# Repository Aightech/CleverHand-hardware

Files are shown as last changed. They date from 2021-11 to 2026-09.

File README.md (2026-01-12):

# CleverHand — Hardware

This repository contains the **hardware implementation** of the CleverHand platform.

CleverHand is an open-source, modular **Human–Machine Interface (HMI) platform** designed for
research, education, and rapid prototyping in neurotechnology, robotics, and human–robot interaction.

The hardware repository provides:

* modular PCB designs (KiCad),
* mechanical integration assets,
* manufacturing outputs,
* and per-module documentation and quality metadata.

> This repository focuses **only on hardware**.
> Firmware, software, tools, and platform-level documentation live in sibling repositories.

---

## Position in the CleverHand platform

CleverHand is structured as a **hardware / firmware / software stack**:

* **Hardware** (this repo)
  Modular, chainable PCBs for sensing, actuation, and interfacing with the human body.

* **Firmware**
  Low-level drivers, bus control, synchronization, and data transport.

* **Software & SDKs**
  Host interfaces (GUI, Python, C++, LSL, ROS, etc.).

This separation allows:

* independent evolution of hardware and software,
* reproducible research setups,
* and multiple integration paths (DIY, PCBA, pre-assembled).

---

## Intended use & scope

CleverHand hardware is designed for:

* research experiments,
* educational use,
* prototyping of assistive and interactive systems.

It is **not**:

* a medical device,
* a certified clinical system,
* a consumer product.

All designs are provided **as-is**, with readiness and quality explicitly documented per module.

---

## Design goals & constraints

| Constraint | Status | Notes |
| --- | :----: | --- |
| Wearable | ⚒️ | Wireless support in progress |
| ≥16 channels | ✅ | Up to 256 channels (32 × 8)  |
| ≥2 kHz bandwidth | ✅ | Up to 2.5 kHz |
| ≥16-bit resolution  | ✅ | Up to 24-bit |
| Bipolar / monopolar | ✅ | Module-dependent |
| Modular | ✅ | 1–32 modules per bus |
| Affordable | ✅ | ~£10–£30 per module |
| Open-source | ✅ | Hardware, firmware, software |

---

## Hardware architecture overview

The hardware platform is built around a **chainable modular architecture**.

Each CleverHand system is composed of:

* a **controller** (host interface and timing),
* one **communication module** (bus arbitration),
* one or more **HMI modules**, assembled from submodules.

### Submodule types

HMI nodes are built by stacking standardized submodules:

* **Communication submodule**
  Address decoding, bus routing, chip-select handling.

* **Sensor submodule**
  Biosignal or motion acquisition (EMG, IMU, etc.).

* **Feedback submodule**
  User feedback (vibration, electrotactile stimulation, LEDs).

* **Interface submodule**
  Physical interface to the body (dry electrodes, jack, flex PCB).

This structure allows:

* rapid reconfiguration,
* high channel density,
* reuse of validated building blocks.

---

## Module catalog (hardware)

> The table below lists **implemented hardware designs**.
> Readiness (prototype / reference) and quality status are tracked via
> `description.yaml`, QC artifacts, and the generated catalog — not inferred from this table.

| Module | Description | Image | Documentation |
| --- | --- | --- | --- |
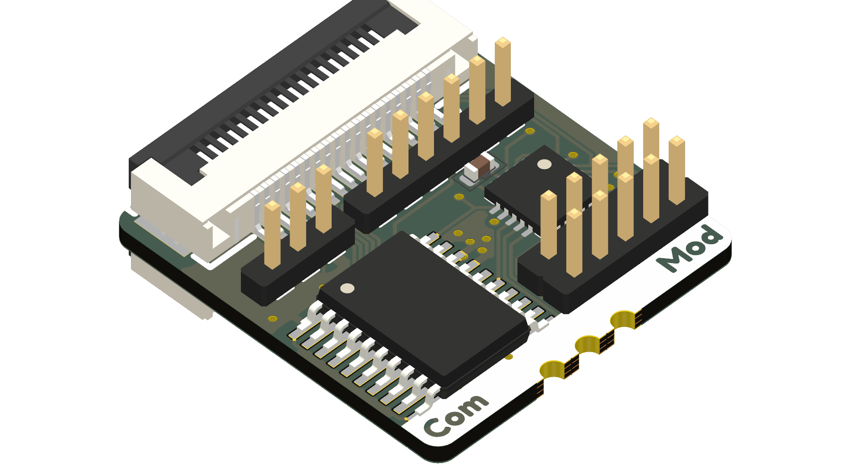
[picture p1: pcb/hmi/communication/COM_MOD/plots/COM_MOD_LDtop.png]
| Communication (COM_MOD) | Bus communication and address decoding |  | [README](pcb/hmi/communication/COM_MOD/README.md) |
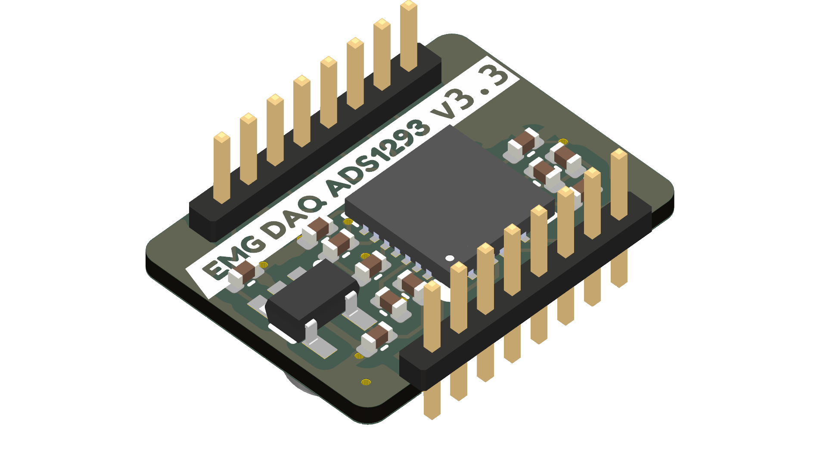
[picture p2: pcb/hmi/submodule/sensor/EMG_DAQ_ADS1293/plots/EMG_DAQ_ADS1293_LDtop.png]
| EMG ADS1293 | 5-channel EMG acquisition |  | [README](pcb/hmi/submodule/sensor/EMG_DAQ_ADS1293/README.md) |
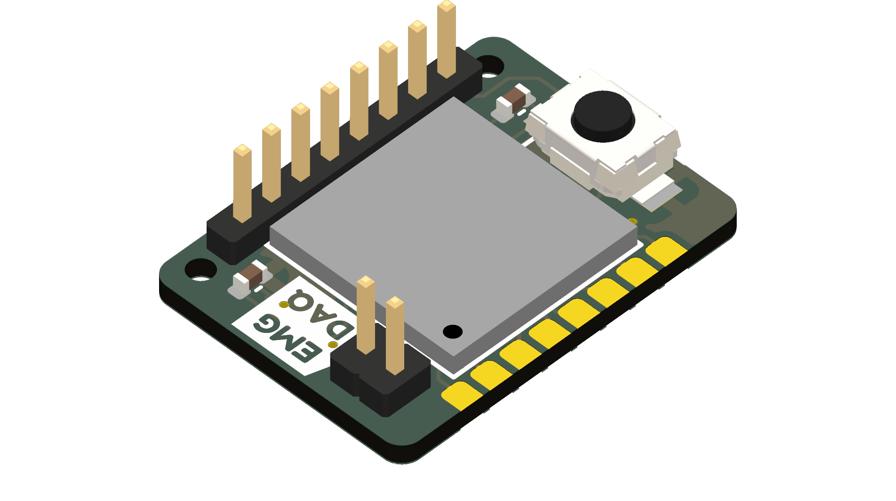
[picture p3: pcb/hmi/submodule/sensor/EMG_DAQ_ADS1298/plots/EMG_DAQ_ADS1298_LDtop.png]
| EMG ADS1298 | 8-channel EMG acquisition |  | [README](pcb/hmi/submodule/sensor/EMG_DAQ_ADS1298/README.md) |
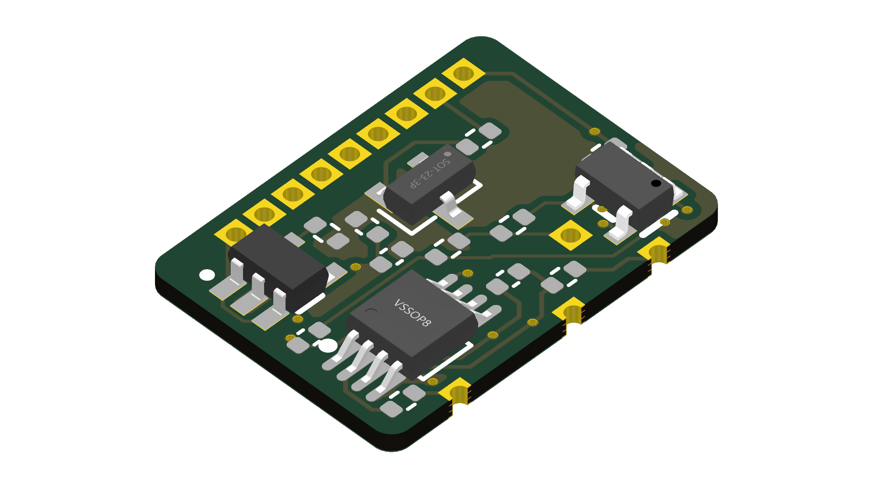
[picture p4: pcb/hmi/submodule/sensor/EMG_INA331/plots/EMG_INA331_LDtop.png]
| EMG INA331 | Single-channel EMG + IMU |  | [README](pcb/hmi/submodule/sensor/EMG_INA331/README.md) |
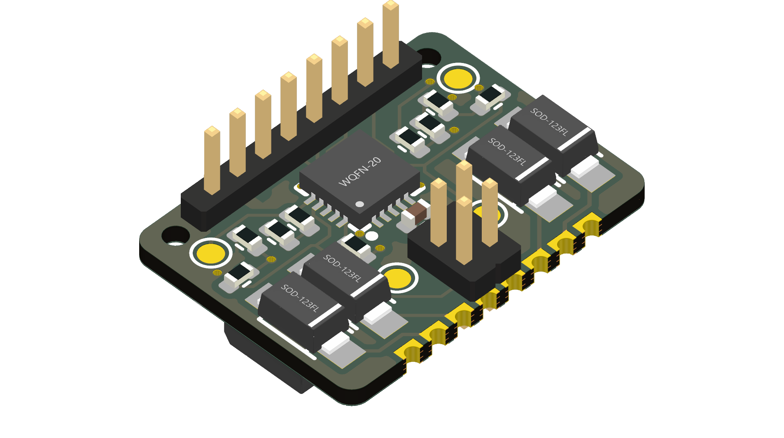
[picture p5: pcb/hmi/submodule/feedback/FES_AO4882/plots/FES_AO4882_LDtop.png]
| FES AO4882 | Electrotactile stimulation |  | [README](pcb/hmi/submodule/feedback/FES_AO4882/README.md) |
| IMU ICM-20948 | 9-axis IMU |  | [README](pcb/hmi/submodule/sensor/IMU_ICM20948/README.md) |
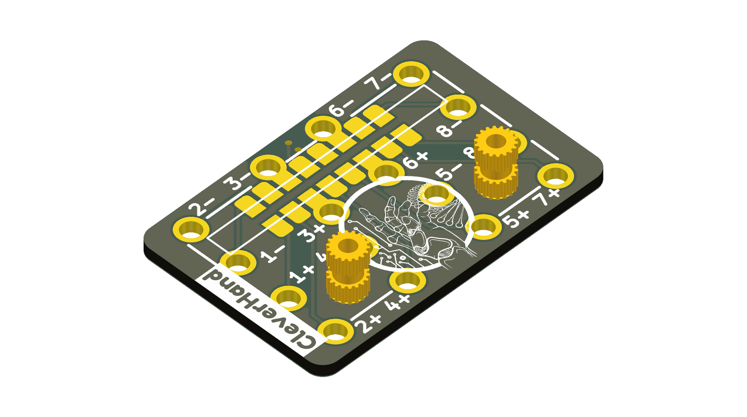
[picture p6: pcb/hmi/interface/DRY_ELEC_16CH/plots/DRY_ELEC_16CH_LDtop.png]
| Dry electrodes (16ch) | Rigid dry electrode interface |  | [README](pcb/hmi/interface/DRY_ELEC_16CH/README.md) |

---

## Bus architecture

CleverHand uses a **shared bus architecture** combining:

* a 5-bit address bus,
* SPI for high-rate data transfer,
* I²C for identification and configuration.

Each communication module:

* monitors the address bus,
* activates the chip-select of the targeted submodule,
* routes SPI transactions accordingly.

System diagram

---

## Addressing & initialization

Module addressing is determined during an initialization phase based on
**physical position in the chain**.

Current status:

* deterministic addressing: **implemented**
* dynamic hot-plugging: **not yet supported**

Future work will refine:

* formal initialization protocol documentation,
* dynamic re-enumeration strategies.

Communication diagram

---

## Evaluation, QC & readiness

Hardware quality and maturity are **explicitly tracked**, not implied.

For each module:

* readiness level is declared in `description.yaml`,
* QC profiles and reports live in the module’s `qc/` folder,
* catalog readiness is generated automatically.

Only **REFERENCE-level modules** are considered stable and suitable
for external reuse without direct support.

---

## Repository structure

This repository contains the hardware designs and supporting assets for the CleverHand platform.

```
├── docs
│   ├── datasheet
│   ├── img
│   ├── initialisation
│   └── plots
├── LICENSE
├── pcb
│   ├── config_file
│   ├── controller
│   ├── hmi
│   └── tool
├── README.md
└── scripts
```

Each top-level directory has a clear, non-overlapping responsibility, described below.

---

## Relation to other repositories

* Firmware: see top-level CleverHand firmware repository
* Software / SDKs: see CleverHand interface repository
* Platform roadmap and policies: see top-level CleverHand README

---

## Status

The CleverHand hardware platform is **actively evolving**.

Some modules are experimental; others are approaching reference quality.
Authoritative status is always given by:

* module metadata,
* QC artifacts,
* and the generated catalog.

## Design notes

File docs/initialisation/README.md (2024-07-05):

# Initialisation Protocol (V2)
## Main Changes
## Changes from V1
The LEDs are used to indicate the internal address of the module. Here are what the LED colours indicate before settling for the final colour:
* Blue: running the main loop.
* Blinks red: adds 1 count/ received a rising edge

The colour of the LED indicates the internal address:
* Red: internal address is 1
* Orange: internal address is 2
* Yellow: internal address is 3
* Green: internal address is 4

In terms of wiring and pin selection, only the FPC cable (communication bus) was used. No extra wires are added to the PCBs.

## Pin Selection

**IO1_out (15)**:
* Read StopState from the previous module
* Allows StopState to be propagated along the chain of modules

**IO1_in (3)**:
* Pulled LOW to stop the next module counting (i.e. send StopState to the next module)
* Allows StopState to be propagated along the chain of modules

**I2C_SCL (20)**: 
* Read CLK signal from the Teensy 4.0 controller 
* Shared between all modules
* Interrupt request (IRQ) is enabled. Each rising edge read by the pin sends a signal to the controller and the interrupt routine is carried out

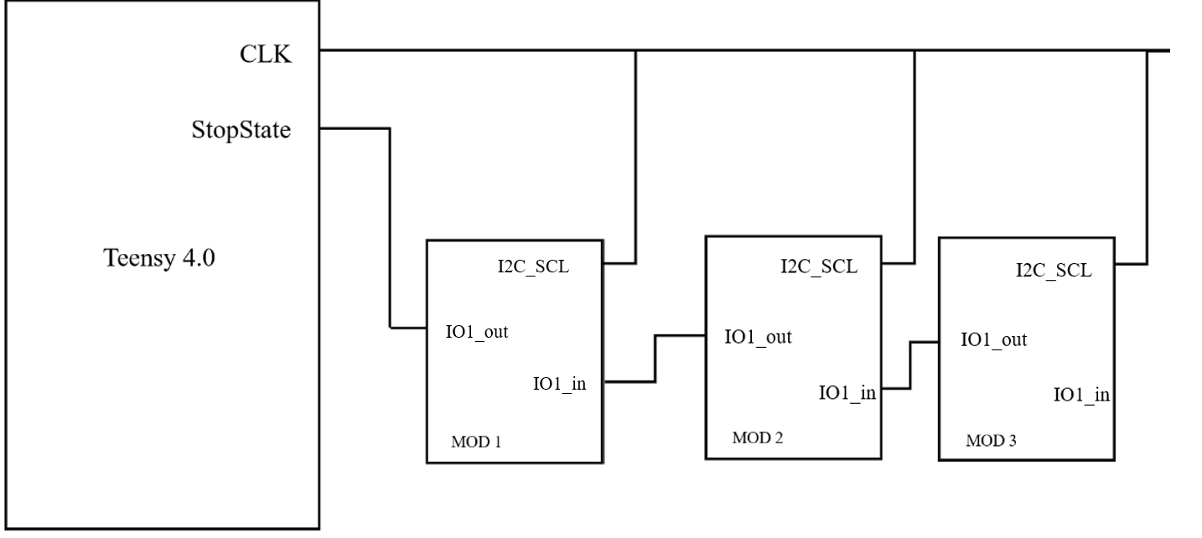
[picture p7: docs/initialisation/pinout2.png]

Fig.1 Pinout

## Method
More information can be found on [hc32l110_clvhd](https://github.com/Aightech/hc32l110_clvhd.git).

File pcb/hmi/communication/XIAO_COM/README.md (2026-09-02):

# XIAO_ADAPTER - Seeed XIAO Adapter Board

Adapter board for using Seeed XIAO ESP32-S3 modules with AxonCtrl ADC modules. Provides a low-cost MCU option for development and testing.

## Hardware

| Component | Type | Comment |
|---|---|---|
| XIAO ESP32-S3 | Module | Seeed Studio module (not included) |
| 2x13 connector | Pin header | Interface to ADC modules |

## Critical Components BOM

| Component | Part Number | Function | Datasheet |
|---|---|---|---|
| MCU Module | XIAO ESP32-S3 | WiFi/BLE microcontroller module | Missing (Seeed product) |
| ADC Connector | ZX-PZ1.0-2-13PWZ | 2x13 pin header to ADC board | - |

**Note:** The XIAO ESP32-S3 module is purchased separately from Seeed Studio.

## Pin Mapping

The XIAO module pins are mapped to the 2x13 ADC connector. See the schematic for detailed routing.

## Compatibility

| ADC Module | Compatible |
|---|---|
| EMG8_ADS1299 | Yes |
| EMG32_RHD2132 | Yes |
| EMG64_RHD2164 | Yes |

## Electrical Schematic
XIAO_ADAPTER_sch

## PCB Layout
XIAO_ADAPTER_pcb

## 3D Model

| Format | Location |
|---|---|
| STEP | [XIAO_ADAPTER.step](plots/XIAO_ADAPTER.step) |
| STL | [XIAO_ADAPTER.stl](plots/XIAO_ADAPTER.stl) |

## Firmware

```bash
source ~/esp/esp-idf/export.sh
cd firmware/esp-idf/axonctrl
idf.py menuconfig  # Select XIAO_ESP32S3 board + ADC module
idf.py -p /dev/ttyACM0 flash monitor
```

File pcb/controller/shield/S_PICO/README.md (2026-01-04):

# pico shield
This shield is made to connect a pico board from seeed studio to the CleverHand bus and control the hmi modules.

## Electrical Schematic
S_PICO_sch

## PCB Layout
|top view|side view|
|---|---|
| COM_MOD_pcb | COM_MOD_pcb |

## 3D Model
[S_PICO_3D](plots/S_PICO_pcb.stl)

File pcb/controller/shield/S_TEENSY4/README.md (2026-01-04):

# XIAO shield
This shield is made to connect a teensy 4 board to the CleverHand bus and control the hmi modules.

## Electrical Schematic
S_TEENSY4_sch

## PCB Layout
|top view|side view|
|---|---|
| COM_MOD_pcb | COM_MOD_pcb |

## 3D Model
[S_TEENSY4_3D](plots/S_TEENSY4_pcb.stl)

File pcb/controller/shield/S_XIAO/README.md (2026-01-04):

# XIAO shield
This shield is made to connect a XIAO board from seeed studio to the CleverHand bus and control the hmi modules.

## Electrical Schematic
S_XIAO_sch

## PCB Layout
|top view|side view|
|---|---|
| COM_MOD_pcb | COM_MOD_pcb |

## 3D Model
[S_XIAO_3D](plots/S_XIAO_pcb.stl)

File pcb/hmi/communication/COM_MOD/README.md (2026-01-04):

# Communication Module
This module is responsible for handling the communication between the different modules of the controller node.

The communication bus is composed of :
- Power supply (3.3V) and ground
- SPI bus (POCI, PICO, SCK)
- I2C bus (SDA, SCL)
- Address bus (A0, A1, A2, A3, A4)
- External reference voltage (AREF)

When the module is connected to the bus, it is assigned an address by the controller node. This address is used to identify the module on the bus.
The communication module will activate the chip select line of the associated sensor module when the address bus matches its address.
Additionally, each module has a unique identifier that is used to identify the module on the I2C bus.

## Electrical Schematic
COM_MOD_sch

## PCB Layout
|top view|side view|
|---|---|
 | COM_MOD_pcb | COM_MOD_pcb |

## 3D Model
[COM_MOD_3D](plots/COM_MOD_pcb.stl)

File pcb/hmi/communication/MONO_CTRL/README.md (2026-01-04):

# Standalone mono-module controller
 This module is a standalone controller node that can be used to control a single submodule. It enanble standalone hmi module without the need for a cleverhand bus.

## Electrical Schematic
MONO_CTRL_sch

## PCB Layout
|top view|side view|
|---|---|
 | MONO_CTRL_pcb | MONO_CTRL_pcb |

## 3D Model
[MONO_CTRL_3D](plots/MONO_CTRL_pcb.stl)

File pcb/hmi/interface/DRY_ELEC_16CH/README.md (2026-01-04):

# Dry Electrodes Module
This module is responsible for interfacing the sensors/actuators inputs/outputs with the user skin or with other modules.

## Electrical Schematic
DRY_ELEC_26CH_sch

## PCB Layout
|top view|side view|
|---|---|
|DRY_ELEC_16CH_pcb|DRY_ELEC_16CH_pcb|

## 3D Model
[DRY_ELEC_16CH_3D](plots/DRY_ELEC_16CH_pcb.stl)

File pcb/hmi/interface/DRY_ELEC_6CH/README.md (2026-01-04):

# Dry Electrodes Module
This module is responsible for interfacing the sensors/actuators inputs/outputs with the user skin or with other modules.

## Electrical Schematic
DRY_ELEC_6CH_sch

## PCB Layout
|top view|side view|
|---|---|
|DRY_ELEC_6CH_pcb|DRY_ELEC_6CH_pcb|

## 3D Model
[DRY_ELEC_6CH_3D](plots/DRY_ELEC_6CH_pcb.stl)

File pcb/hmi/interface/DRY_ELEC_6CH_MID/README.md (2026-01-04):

# Dry Electrodes Module
This module is responsible for interfacing the sensors/actuators inputs/outputs with the user skin or with other modules.

## Electrical Schematic
DRY_ELEC_6CH_MID_sch

## PCB Layout
|top view|side view|
|---|---|
|DRY_ELEC_6CH_MID_pcb|DRY_ELEC_6CH_MID_pcb|

## 3D Model
[DRY_ELEC_6CH_MID_3D](plots/DRY_ELEC_6CH_MID_pcb.stl)

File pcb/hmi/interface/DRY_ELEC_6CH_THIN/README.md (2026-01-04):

# Dry Electrodes Module
This module is responsible for interfacing the sensors/actuators inputs/outputs with the user skin or with other modules.

## Electrical Schematic
DRY_ELEC_6CH_THIN_sch

## PCB Layout
|top view|side view|
|---|---|
|DRY_ELEC_6CH_THIN_pcb|DRY_ELEC_6CH_THIN_pcb|

## 3D Model
[DRY_ELEC_6CH_THIN_3D](plots/DRY_ELEC_6CH_THIN_pcb.stl)

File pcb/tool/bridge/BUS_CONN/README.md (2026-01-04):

# Bus Connection
This module is a passive bridge to easily access the cleverhand bus tracks.

## Electrical Schematic
BUS_CONN_sch

## PCB Layout
| top | bottom |
| --- | --- |
|BUS_CONN_pcb | BUS_CONN_pcb |

## 3D Model
[BUS_CONN_3D](plots/BUS_CONN_pcb.stl)

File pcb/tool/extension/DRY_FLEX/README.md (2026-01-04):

# Flex Interface Module
This module extends the electrodes module. It a flexible PCB that connects the electrodes module and offers a flexible interface to the user.

## Electrical Schematic
DRY_ELEC_26CH_sch

## PCB Layout
|top view|side view|
|---|---|
|DRY_FLEX_pcb|DRY_FLEX_pcb|

## 3D Model
[DRY_FLEX_3D](plots/DRY_FLEX_pcb.stl)

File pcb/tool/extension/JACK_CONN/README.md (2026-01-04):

# Jack Connection
 This extension board let you connect a hmi module (with a 4x4 dry interface) to jack connector. 

## Electrical Schematic
JACK_CONN_sch

## PCB Layout
|top view|side view|
|---|---|
 | JACK_CONN_pcb | JACK_CONN_pcb |

## 3D Model
[JACK_CONN_3D](plots/JACK_CONN_pcb.stl)

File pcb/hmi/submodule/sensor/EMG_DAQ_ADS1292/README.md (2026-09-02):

# EMG ADS1292 Module
This module is a data acquisition module that embeds the ADS1292 analog front-end. It is responsible for acquiring the EMG signals from the electrodes.

## Electrical Schematic
EMG_DAQ_ADS1292_sch

## PCB Layout
|top view|side view|
|---|---|
 | EMG_DAQ_ADS1292_pcb | EMG_DAQ_ADS1292_pcb |

## 3D Model
[EMG_DAQ_ADS1292_3D](plots/EMG_DAQ_ADS1292_pcb.stl)

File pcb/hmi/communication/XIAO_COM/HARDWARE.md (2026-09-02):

# XIAO_ADAPTER

## Overview
Adapter board for interfacing Seeed Studio XIAO modules with the ADS1299 ADC boards. Used for rapid prototyping and POC development.

## Basic Information

| Field | Value |
|---|---|
| **Board Name** | XIAO_ADAPTER |
| **Version** | 1.0 |
| **Status** | Active - Prototype |
| **Created** | August 2025 |
| **Last Modified** | January 2026 |
| **Designer** | adev |

## Purpose

- Interface for Seeed Studio XIAO ESP32-S3/C6 modules
- Quick prototyping without custom MCU board
- POC validation platform

## Supported XIAO Modules

- XIAO ESP32-S3
- XIAO ESP32-C6

## Compatibility

| Component | Compatible Versions |
|---|---|
| **ADC Board** | EMG8_ADS1299 v1.0+ |
| **Firmware** | v0.1+ (Arduino) |
| **Driver** | ads1299_udp v1.0.0+ |

## Manufacturing

- **Fabrication:** JLCPCB

## Changelog

### v1.0 (August 2025)
- Initial adapter design for XIAO modules
- POC development platform

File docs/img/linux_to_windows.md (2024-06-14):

# hc32l110 template from Linux to Windows
## Prerequistes 
* DAPLink
* Communication module with hc332l110 microcontroller
* Makefile and rules.mk from [hc32l110 template](https://github.com/IOsetting/hc32l110-template)

### 1. Install GNU Arm Embedded Toolchain
First, download the toolchain from Arm GNU Toolchain Downloads. Select the suitable Arm GNU Toolchain for your host (mingw-w64-i686 for Windows 10 or later) and toolchain target. For windows users and bare-metal targets, download *arm-gnu-toolchain-13.2.rel1-mingw-w64-i686-arm-none-eabi.zip*. Zip file was selected based on personal preference as the path to the file is easier to locate. Use a third-party software to extract the files in the zip file. This is because extracting with the in-built windows “extract all” function returned error 0x80010135, which mainly happens due to exceeding Windows' 260-character limit. [7-zip](https://www.7-zip.org/) for windows x64 was downloaded and used. The path to the extracted file is then input into the makefile.

### 2. Install PyOCD
To install PyOCD, one must make sure that the latest version of pip is installed in the computer. Also, make sure that pip is added to the PATH system variable. This can be done by editing the environmental variable in the control panel. Use pip to install PyOCD by running:

`py -m pip install pyocd`

and verify the installation by running:

`pyocd --version`

in the command prompt.

### 3. Install MAKE
Download the latest version of Make for Windows on [GNUWin 32](https://gnuwin32.sourceforge.net/packages/make.htm). It includes a complete package, except sources. Add the bin directory of the downloaded file to the PATH system variable and verify installation by running:

`Make --version`

### 4. Clone the repository  
The repository from [hc32l110 template](https://github.com/IOsetting/hc32l110-template) was cloned to a local workspace on VSCode. 

## Amendments to the makefile
### 1. ARM_TOOLCHAIN
Changed the path to ARM_TOOLCHAIN. Note that for windows, backslash \ is used instead of slash /. For example, the path to ARM_TOOLCHAIN would look something like:

`C:\\Users\\<name_of_user>\\<location_of_file>\\arm-gnu-toolchain-13.2.rel1-mingw-w64-i686-arm-none-eabi\\arm-gnu-toolchain-13.2.Rel1-mingw-w64-i686-arm-none-eabi\\bin`

It should be pointed to the bin directory of the file. 

### 2. FLASH_PROGRM
PyOCD was selected as DAPLink was used. Therefore:

`FLASH_PROGRM    ?= pyocd`

### 3. /
All the slashes / are changed to backslashes \ so that it is compatible with Windows syntax.

## Amendments to rules.mk
### 1. CSOURCE and CFILES
The original rules.mk from the repository uses the Linux FIND command to locate the c sources files in the library and to add them to CSOURCES. However, the FIND command does not exist for Windows. CFILES were therefore added manually as follows:

```
CFILES := Libraries\\CMSIS\\HC32L110\\source\\system_hc32l110.c
CFILES += User\\main.c # Adding individual c source files
```
All subfiles in the *HC32L110_Driver* in the *Libraries* file were added manually. Besides, a CSOURCES variable was defined using the ‘wildcard’ function for windows to locate the c source files. However, this did not workout perfectly well. Therefore, one extra line of code was written for the definition of CSOURCES:
```
CSOURCES := $(foreach dir, $(CDIRS), $(wildcard $(TOP)\\$(dir)\\*.c))
CSOURCES += $(addprefix $(TOP)\\, $(CFILES))
```
Overall, a list of c source files is compiled.

### 2.	Compiling 
This is the original code:
```make
# Compile c to obj -- should be `$(BDIR)/%.o: $(TOP)/%.c`, but since $(TOP) is base folder so non-path also works
$(BDIR)/%.o: $(TOP)/%.c
    @printf "  CC\t$<\n"
    @mkdir -p $(dir $@)
    $(Q)$(CC) $(TGT_CFLAGS) $(TGT_INCFLAGS) -MT $@ -o $@ -c $< -MD -MF $(BDIR)/$*.d -MP

# Compile asm to obj
$(BDIR)/%.o: $(TOP)/%.s
    @printf "  AS\t$<\n"
    @mkdir -p $(dir $@)
    $(Q)$(CC) $(TGT_ASFLAGS) -o $@ -c $<

# Link object files to elf
$(BDIR)/$(PROJECT).elf: $(OBJS) $(TOP)/$(LDSCRIPT)
    @printf "  LD\t$(LDSCRIPT) -> $@\n"
    $(Q)$(CC) $(TGT_LDFLAGS) -T$(TOP)/$(LDSCRIPT) $(OBJS) -o $@

# Convert elf to bin
%.bin: %.elf
    @printf "  OBJCP BIN\t$@\n"
    $(Q)$(OBJCOPY) -I elf32-littlearm -O binary  $< $@

# Convert elf to hex
%.hex: %.elf
    @printf "  OBJCP HEX\t$@\n"
    $(Q)$(OBJCOPY) -I elf32-littlearm -O ihex  $< $@
```

The ‘printf’ command is not readily available on Windows. Similarly, the ‘mkdir -p’ command that exists for Linux but not Windows. This section of the code set the rules for compiling the c source files and assembly files into object files, links the object files into an ELF executable, and to binary and hex formats. For example, the first 5 lines compiles c source files to object files, and creates a new directory using ‘mkdir -p’ if the directory does not initially exists. To do this in Windows, ‘printf’ commands were replaced with ‘echo’, and ‘mkdir -p’ were replaced with ‘if not exist’. Here is the amended version:
```make
# Compile C to obj
$(BDIR)\\%.o: $(TOP)\\%.c
    @echo "  CC  $<"
    @if not exist $(dir $@) mkdir $(dir $@)
    $(Q)$(CC) $(TGT_CFLAGS) $(TGT_INCFLAGS) -MT $@ -o $@ -c $< -MD -MF $(BDIR)\\$*.d -MP

# Compile ASM to obj
$(BDIR)\\%.o: $(TOP)\\%.s
    @echo "  AS  $<"
    @if not exist $(dir $@) mkdir $(dir $@)
    $(Q)$(CC) $(TGT_ASFLAGS) -o $@ -c $<

# Link object files to ELF
$(BDIR)\\$(PROJECT).elf: $(OBJS) $(TOP)\\$(LDSCRIPT)
    @echo "  LD  $(LDSCRIPT) -> $@"
    $(Q)$(CC) $(TGT_LDFLAGS) -T$(TOP)\\$(LDSCRIPT) $(OBJS) -o $@

# Convert ELF to BIN
%.bin: %.elf
    @echo "  OBJCP BIN $@"
    $(Q)$(OBJCOPY) -I elf32-littlearm -O binary $< $@

# Convert ELF to HEX
%.hex: %.elf
    @echo "  OBJCP HEX $@"
    $(Q)$(OBJCOPY) -I elf32-littlearm -O ihex $< $@
```

### 3. /
All the slashes / are changed to backslashes \ so that it is compatible with Windows syntax.

## Compiling and uploading the code
When make clean and make are run in the terminal, the following output was given:
```
C:\Users\<name_of_user>\<location_of_file>\hc32l110_clvhd(2)\hc32l110_clvhd(2)>make clean

if exist .\\Build rd /s /q .\\Build

C:\Users\<name_of_user>\<location_of_file>\hc32l110_clvhd(2)\hc32l110_clvhd(2)>make

"  CC  .\\\Libraries\\CMSIS\\HC32L110\\source\\system_hc32l110.c"
"  CC  .\\\User\\main.c"
"  CC  .\\\Libraries\\HC32L110_Driver\\src\\adc.c"
"  CC  .\\\Libraries\\HC32L110_Driver\\src\\adt.c"
"  CC  .\\\Libraries\\HC32L110_Driver\\src\\base_timer.c"
"  CC  .\\\Libraries\\HC32L110_Driver\\src\\clk.c"
"  CC  .\\\Libraries\\HC32L110_Driver\\src\\crc.c"
"  CC  .\\\Libraries\\HC32L110_Driver\\src\\ddl.c"
"  CC  .\\\Libraries\\HC32L110_Driver\\src\\flash.c"
"  CC  .\\\Libraries\\HC32L110_Driver\\src\\gpio.c"
"  CC  .\\\Libraries\\HC32L110_Driver\\src\\i2c.c"
"  CC  .\\\Libraries\\HC32L110_Driver\\src\\interrupts_hc32l110.c"
"  CC  .\\\Libraries\\HC32L110_Driver\\src\\lpm.c"
"  CC  .\\\Libraries\\HC32L110_Driver\\src\\lpt.c"
"  CC  .\\\Libraries\\HC32L110_Driver\\src\\lpuart.c"
"  CC  .\\\Libraries\\HC32L110_Driver\\src\\lvd.c"
"  CC  .\\\Libraries\\HC32L110_Driver\\src\\pca.c"
"  CC  .\\\Libraries\\HC32L110_Driver\\src\\reset.c"
"  CC  .\\\Libraries\\HC32L110_Driver\\src\\rgb.c"
"  CC  .\\\Libraries\\HC32L110_Driver\\src\\rtc.c"
"  CC  .\\\Libraries\\HC32L110_Driver\\src\\spi.c"
"  CC  .\\\Libraries\\HC32L110_Driver\\src\\trim.c"
"  CC  .\\\Libraries\\HC32L110_Driver\\src\\uart.c"
"  CC  .\\\Libraries\\HC32L110_Driver\\src\\vc.c"
"  CC  .\\\Libraries\\HC32L110_Driver\\src\\wdt.c"
"  AS  .\\\Libraries\\CMSIS\\HC32L110\\source\\startup_hc32l110.s"
"  LD  Libraries\\LDScripts\\hc32l110x4.ld -> .\\Build\\app.elf"
C:/Users/Byron Chan/Documents/trial/arm-gnu-toolchain-13.2.rel1-mingw-w64-i686-arm-none-eabi/arm-gnu-toolchain-13.2.Rel1-mingw-w64-i686-arm-none-eabi/bin/../lib/gcc/arm-none-eabi/13.2.1/../../../../arm-none-eabi/bin/ld.exe: C:/Users/Byron Chan/Documents/trial/arm-gnu-toolchain-13.2.rel1-mingw-w64-i686-arm-none-eabi/arm-gnu-toolchain-13.2.Rel1-mingw-w64-i686-arm-none-eabi/bin/../lib/gcc/arm-none-eabi/13.2.1/thumb/v6-m/nofp\libc_nano.a(libc_a-closer.o): in function `_close_r':
closer.c:(.text._close_r+0xc): warning: _close is not implemented and will always fail
C:/Users/Byron Chan/Documents/trial/arm-gnu-toolchain-13.2.rel1-mingw-w64-i686-arm-none-eabi/arm-gnu-toolchain-13.2.Rel1-mingw-w64-i686-arm-none-eabi/bin/../lib/gcc/arm-none-eabi/13.2.1/../../../../arm-none-eabi/bin/ld.exe: C:/Users/Byron Chan/Documents/trial/arm-gnu-toolchain-13.2.rel1-mingw-w64-i686-arm-none-eabi/arm-gnu-toolchain-13.2.Rel1-mingw-w64-i686-arm-none-eabi/bin/../lib/gcc/arm-none-eabi/13.2.1/thumb/v6-m/nofp\libc_nano.a(libc_a-lseekr.o): in function `_lseek_r':
lseekr.c:(.text._lseek_r+0x10): warning: _lseek is not implemented and will always fail
C:/Users/Byron Chan/Documents/trial/arm-gnu-toolchain-13.2.rel1-mingw-w64-i686-arm-none-eabi/arm-gnu-toolchain-13.2.Rel1-mingw-w64-i686-arm-none-eabi/bin/../lib/gcc/arm-none-eabi/13.2.1/../../../../arm-none-eabi/bin/ld.exe: C:/Users/Byron Chan/Documents/trial/arm-gnu-toolchain-13.2.rel1-mingw-w64-i686-arm-none-eabi/arm-gnu-toolchain-13.2.Rel1-mingw-w64-i686-arm-none-eabi/bin/../lib/gcc/arm-none-eabi/13.2.1/thumb/v6-m/nofp\libc_nano.a(libc_a-readr.o): in function `_read_r':
readr.c:(.text._read_r+0x10): warning: _read is not implemented and will always fail
C:/Users/Byron Chan/Documents/trial/arm-gnu-toolchain-13.2.rel1-mingw-w64-i686-arm-none-eabi/arm-gnu-toolchain-13.2.Rel1-mingw-w64-i686-arm-none-eabi/bin/../lib/gcc/arm-none-eabi/13.2.1/../../../../arm-none-eabi/bin/ld.exe: C:/Users/Byron Chan/Documents/trial/arm-gnu-toolchain-13.2.rel1-mingw-w64-i686-arm-none-eabi/arm-gnu-toolchain-13.2.Rel1-mingw-w64-i686-arm-none-eabi/bin/../lib/gcc/arm-none-eabi/13.2.1/thumb/v6-m/nofp\libc_nano.a(libc_a-writer.o): in function `_write_r':
writer.c:(.text._write_r+0x10): warning: _write is not implemented and will always fail
C:/Users/Byron Chan/Documents/trial/arm-gnu-toolchain-13.2.rel1-mingw-w64-i686-arm-none-eabi/arm-gnu-toolchain-13.2.Rel1-mingw-w64-i686-arm-none-eabi/bin/../lib/gcc/arm-none-eabi/13.2.1/../../../../arm-none-eabi/bin/ld.exe: warning: .\\Build\\app.elf has a LOAD segment with RWX permissions
Memory region         Used Size  Region Size  %age Used
             RAM:        1112 B         2 KB     54.30%
           FLASH:        8576 B        16 KB     52.34%
"  OBJCP BIN .\\Build\\app.bin"
"  OBJCP HEX .\\Build\\app.hex"
"Build successful! Output files are in .\\Build"
```
When make flash is run, the following output was given:
```
C:\Users\<name_of_user>\<location_of_file>\hc32l110_clvhd(2)\hc32l110_clvhd(2)>make flash
"Flashing with pyocd"
"Else if is else if-ing"
pyocd erase -c -t hc32l110c4ua --config ".\\Misc\\pyocd.yaml"
0000921 W STLink, CMSIS-DAPv2 and PicoProbe probes are not supported because no libusb library was found. [common]
0001087 I Erasing chip...[eraser]
0001400 I Chip erase complete [eraser]
pyocd load. \\Build\\app.hex -t hc32l110 --config ".\\Misc\\pyocd.yaml"
0000882 W STLink, CMSIS-DAPv2 and PicoProbe probbes are not supported because no libusb library was found. [common]
0001052 I Loading C:\Users\<name_of_user>\<location_of_file>\hc32l110_clvhd\Build\app.hex [load_cmd]
[==================================================] 100%
0003217 I Erased 3584 bytes (7 sectors), programmed 3584 bytes (7 pages), skipped 0 bytes (0 pages) at 1.62 kB/s [loader]
```

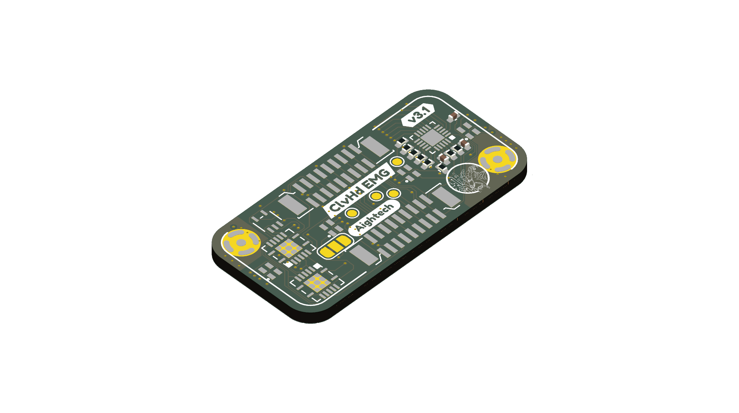
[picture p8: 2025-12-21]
docs/plots/cleverhand_emg_LDtop.png

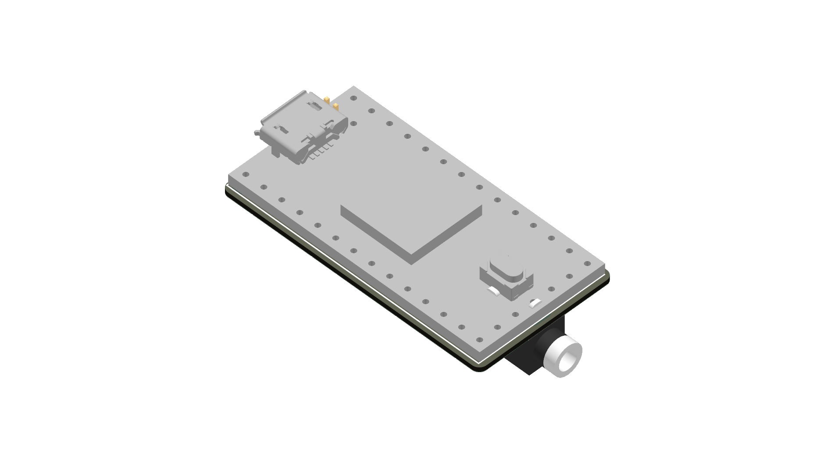
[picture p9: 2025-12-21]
docs/plots/CONTROLLER_teensy4_LDtop.png

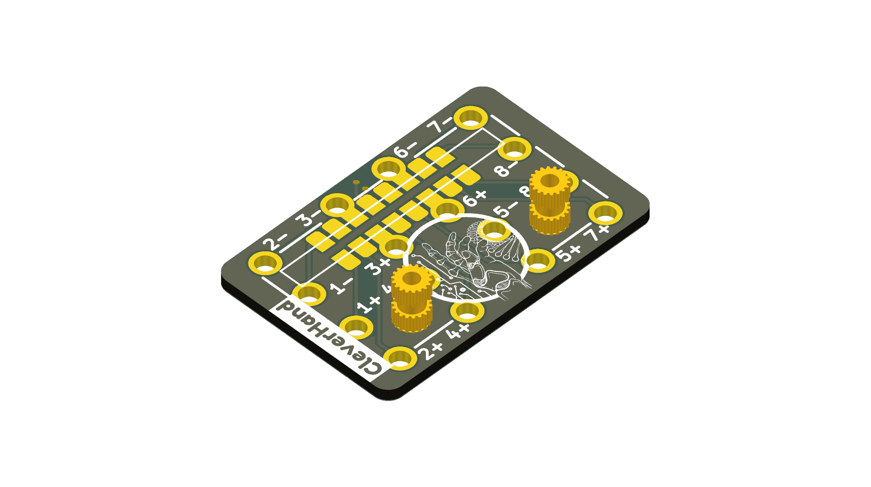
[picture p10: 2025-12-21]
docs/plots/DRY_ELECTRODES_LDtop.png

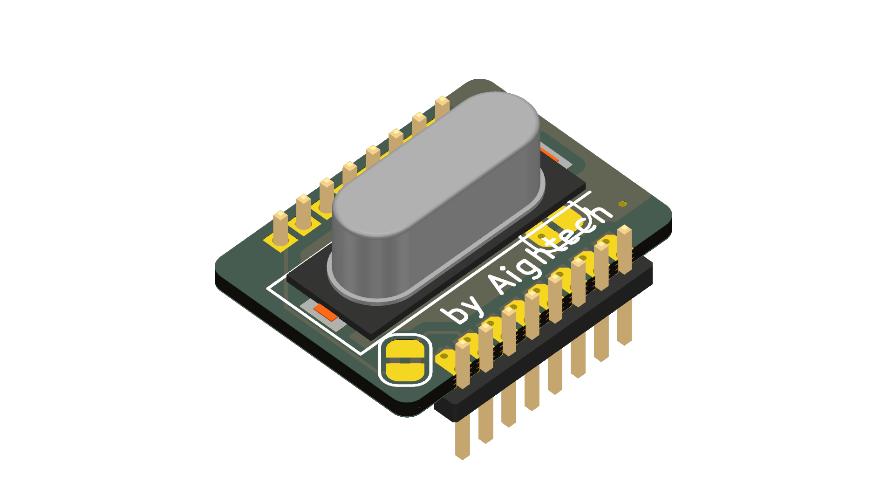
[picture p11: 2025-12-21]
docs/plots/EMG_DAQ_ADS1293_LDbot.png

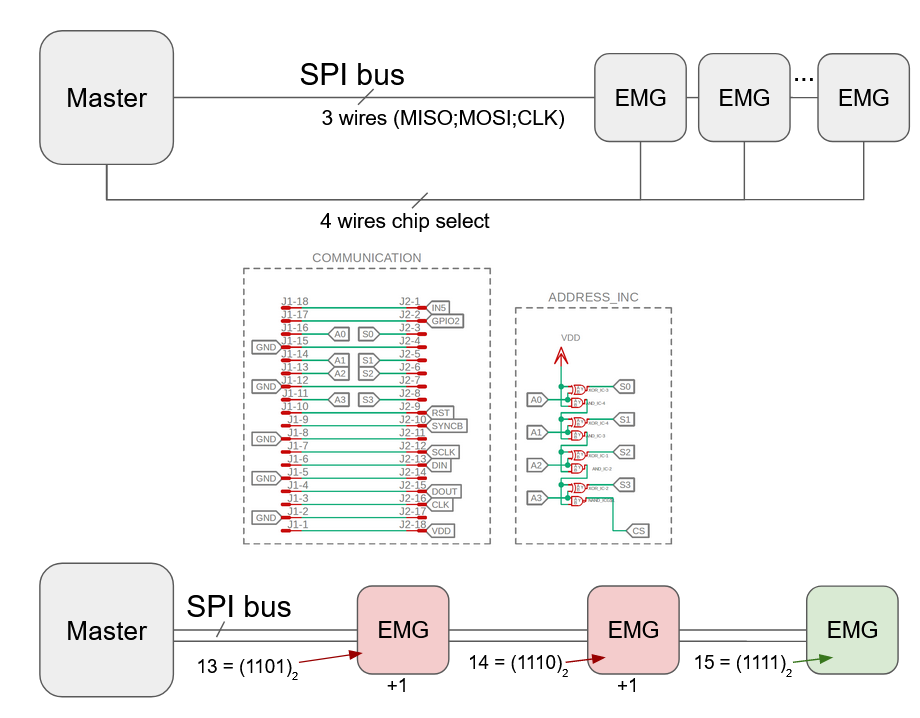
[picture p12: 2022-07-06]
docs/img/chipSelect.PNG

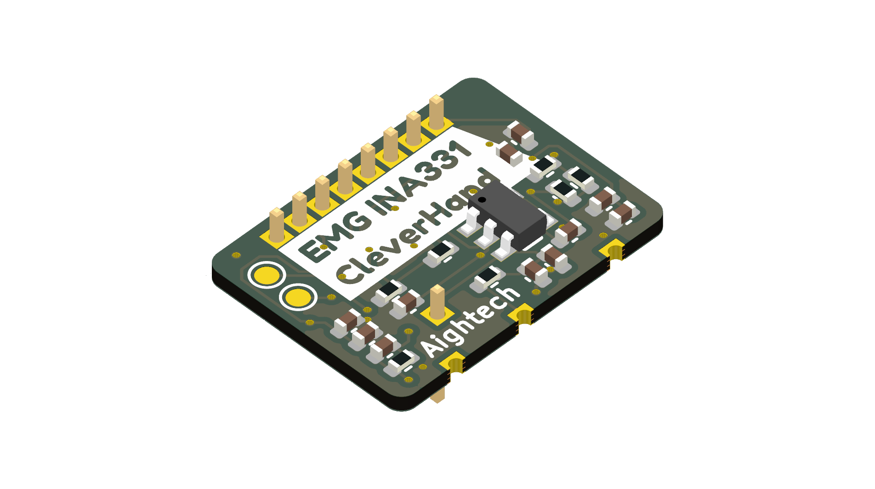
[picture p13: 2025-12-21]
docs/plots/EMG_INA331_LDbot.png

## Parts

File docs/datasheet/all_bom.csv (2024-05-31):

Reference | Value | Footprint | DNP | LCSC
J1 | XF2J-1824-12A | 00_custom-footprints:XF2J-1824-12A
J3 | jack2.5_PJ-210B | 00_custom-footprints:Jack_Socket_PJ-210B
J4 | Conn_01x20_Male | Connector_PinHeader_2.54mm:PinHeader_1x20_P2.54mm_Vertical
J5 | Conn_01x20_Male | Connector_PinHeader_2.54mm:PinHeader_1x20_P2.54mm_Vertical
J6 | Conn_01x03_Male | Connector_PinHeader_2.54mm:PinHeader_1x03_P2.54mm_Vertical
J7 | Conn_01x03_Male | Connector_PinHeader_2.54mm:PinHeader_1x03_P2.54mm_Vertical
FPC2 | FPC-05F-18PH20 | 00_lcsc:FPC-SMD_18P-P0.50_X05C2018TZ |  | C2856802
J5 | jack2.5_PJ-210B | 00_custom-footprints:Jack_Socket_PJ-210B
U1 | Teensy4.0 | 00_custom-footprints:Teensy40_simple
C1 | 4.7uF | Capacitor_SMD:C_0402_1005Metric
FPC1 | FPC-05F-18PH20 | 00_lcsc:FPC-SMD_18P-P0.50_FPC-05F-18PH20 |  | C2856802
FPC2 | FPC-05F-18PH20 | 00_lcsc:FPC-SMD_18P-P0.50_FPC-05F-18PH20 |  | C2856802
I1 | smd_insert | 00_Custom:insert_1.2mm
LED1 | WS2812C-2020-V1 | 00_lcsc:LED-SMD_4P-L2.0-W2.0-TL_WS2812B-2020 |  | C2976072
LED2 | WS2812C | 00_lcsc:LED-SMD_4P-L2.0-W2.0-TL_WS2812B-2020 |  | C2976072
R1 | 10K | Resistor_SMD:R_0402_1005Metric
SW1 | TS-1088R-02026 | 00_lcsc:SW-SMD_L3.9-W3.0-P4.45 |  | C455280
U1 | HC32L110C6UA | 00_Custom:QFN-20-1EP_3x3mm_P0.4mm_EP1.4x1.4mm
U2 | 74HC688 | digikey-footprints:TSSOP-20_W4.4mm
I3 | smd_insert | 00_custom-footprints:insert_1.2mm
I4 | smd_insert | 00_custom-footprints:insert_1.2mm
J1 | Conn_01x01_Pin | 00_custom-footprints:SolderWirePad_1x01_SMD_1x2mm
J2 | Conn_01x01_Pin | 00_custom-footprints:SolderWirePad_1x01_SMD_1x2mm
J3 | Conn_01x01_Pin | 00_custom-footprints:SolderWirePad_1x01_SMD_1x2mm
J4 | Conn_01x01_Pin | 00_custom-footprints:SolderWirePad_1x01_SMD_1x2mm
J5 | Conn_01x01_Pin | 00_custom-footprints:SolderWirePad_1x01_SMD_1x2mm
J6 | Conn_01x01_Pin | 00_custom-footprints:SolderWirePad_1x01_SMD_1x2mm
J7 | Conn_01x01_Pin | 00_custom-footprints:SolderWirePad_1x01_SMD_1x2mm
J8 | Conn_01x01_Pin | 00_custom-footprints:SolderWirePad_1x01_SMD_1x2mm
J9 | Conn_01x01_Pin | 00_custom-footprints:SolderWirePad_1x01_SMD_1x2mm
J10 | Conn_01x01_Pin | 00_custom-footprints:SolderWirePad_1x01_SMD_1x2mm
J11 | Conn_01x01_Pin | 00_custom-footprints:SolderWirePad_1x01_SMD_1x2mm
J12 | Conn_01x01_Pin | 00_custom-footprints:SolderWirePad_1x01_SMD_1x2mm
J13 | Conn_01x01_Pin | 00_custom-footprints:SolderWirePad_1x01_SMD_1x2mm
J14 | Conn_01x01_Pin | 00_custom-footprints:SolderWirePad_1x01_SMD_1x2mm
J15 | Conn_01x01_Pin | 00_custom-footprints:SolderWirePad_1x01_SMD_1x2mm
J16 | Conn_01x01_Pin | 00_custom-footprints:SolderWirePad_1x01_SMD_1x2mm
J17 | Conn_01x01_Pin | 00_custom-footprints:Pin_D1.2mm_pogo
J18 | Conn_01x01_Pin | 00_custom-footprints:Pin_D1.2mm_pogo
J19 | Conn_01x01_Pin | 00_custom-footprints:Pin_D1.2mm_pogo
J20 | Conn_01x01_Pin | 00_custom-footprints:Pin_D1.2mm_pogo
J21 | Conn_01x01_Pin | 00_custom-footprints:Pin_D1.2mm_pogo
J22 | Conn_01x01_Pin | 00_custom-footprints:Pin_D1.2mm_pogo
J23 | Conn_01x01_Pin | 00_custom-footprints:Pin_D1.2mm_pogo
J24 | Conn_01x01_Pin | 00_custom-footprints:Pin_D1.2mm_pogo
J25 | Conn_01x01_Pin | 00_custom-footprints:Pin_D1.2mm_pogo
J26 | Conn_01x01_Pin | 00_custom-footprints:Pin_D1.2mm_pogo
J27 | Conn_01x01_Pin | 00_custom-footprints:Pin_D1.2mm_pogo
J28 | Conn_01x01_Pin | 00_custom-footprints:Pin_D1.2mm_pogo
J29 | Conn_01x01_Pin | 00_custom-footprints:Pin_D1.2mm_pogo
J30 | Conn_01x01_Pin | 00_custom-footprints:Pin_D1.2mm_pogo
J31 | Conn_01x01_Pin | 00_custom-footprints:Pin_D1.2mm_pogo
J32 | Conn_01x01_Pin | 00_custom-footprints:Pin_D1.2mm_pogo
J1 | Conn_01x01_Pin | 00_custom-footprints:Pin_D1.2mm_pogo
J2 | Conn_01x01_Pin | 00_custom-footprints:Pin_D1.2mm_pogo
J3 | Conn_01x01_Pin | 00_custom-footprints:Pin_D1.2mm_pogo
J4 | Conn_01x01_Pin | 00_custom-footprints:Pin_D1.2mm_pogo
J5 | Conn_01x01_Pin | 00_custom-footprints:Pin_D1.2mm_pogo
J6 | Conn_01x01_Pin | 00_custom-footprints:Pin_D1.2mm_pogo
J7 | Conn_01x01_Pin | 00_custom-footprints:Pin_D1.2mm_pogo
J8 | Conn_01x01_Pin | 00_custom-footprints:Pin_D1.2mm_pogo
J9 | Conn_01x01_Pin | 00_custom-footprints:Pin_D1.2mm_pogo
J10 | Conn_01x01_Pin | 00_custom-footprints:Pin_D1.2mm_pogo
J11 | Conn_01x01_Pin | 00_custom-footprints:Pin_D1.2mm_pogo
J12 | Conn_01x01_Pin | 00_custom-footprints:Pin_D1.2mm_pogo
J13 | Conn_01x01_Pin | 00_custom-footprints:Pin_D1.2mm_pogo
J14 | Conn_01x01_Pin | 00_custom-footprints:Pin_D1.2mm_pogo
J15 | Conn_01x01_Pin | 00_custom-footprints:Pin_D1.2mm_pogo
J16 | Conn_01x01_Pin | 00_custom-footprints:Pin_D1.2mm_pogo
J17 | Conn_01x01_Pin | 00_custom-footprints:Pin_D1.2mm_pogo
J18 | Conn_01x01_Pin | 00_custom-footprints:Pin_D1.2mm_pogo
J19 | Conn_01x01_Pin | 00_custom-footprints:Pin_D1.2mm_pogo
J20 | Conn_01x01_Pin | 00_custom-footprints:Pin_D1.2mm_pogo
J21 | Conn_01x01_Pin | 00_custom-footprints:Pin_D1.2mm_pogo
J22 | Conn_01x01_Pin | 00_custom-footprints:Pin_D1.2mm_pogo
J23 | Conn_01x01_Pin | 00_custom-footprints:Pin_D1.2mm_pogo
J24 | Conn_01x01_Pin | 00_custom-footprints:Pin_D1.2mm_pogo
J25 | Conn_01x01_Pin | 00_custom-footprints:Pin_D1.2mm_pogo
J26 | Conn_01x01_Pin | 00_custom-footprints:Pin_D1.2mm_pogo
J27 | Conn_01x01_Pin | 00_custom-footprints:Pin_D1.2mm_pogo
J28 | Conn_01x01_Pin | 00_custom-footprints:Pin_D1.2mm_pogo
J29 | Conn_01x01_Pin | 00_custom-footprints:Pin_D1.2mm_pogo
J30 | Conn_01x01_Pin | 00_custom-footprints:Pin_D1.2mm_pogo
J31 | Conn_01x01_Pin | 00_custom-footprints:Pin_D1.2mm_pogo
J32 | Conn_01x01_Pin | 00_custom-footprints:Pin_D1.2mm_pogo
TP1 | TestPoint | 00_custom-footprints:SolderWirePad_1x01_SMD_1x2mm
TP2 | TestPoint | 00_custom-footprints:SolderWirePad_1x01_SMD_1x2mm
TP3 | TestPoint | 00_custom-footprints:SolderWirePad_1x01_SMD_1x2mm
TP4 | TestPoint | 00_custom-footprints:SolderWirePad_1x01_SMD_1x2mm
TP5 | TestPoint | 00_custom-footprints:SolderWirePad_1x01_SMD_1x2mm
TP6 | TestPoint | 00_custom-footprints:SolderWirePad_1x01_SMD_1x2mm
TP7 | TestPoint | 00_custom-footprints:SolderWirePad_1x01_SMD_1x2mm
TP8 | TestPoint | 00_custom-footprints:SolderWirePad_1x01_SMD_1x2mm
TP9 | TestPoint | 00_custom-footprints:SolderWirePad_1x01_SMD_1x2mm
TP10 | TestPoint | 00_custom-footprints:SolderWirePad_1x01_SMD_1x2mm
TP11 | TestPoint | 00_custom-footprints:SolderWirePad_1x01_SMD_1x2mm
TP12 | TestPoint | 00_custom-footprints:SolderWirePad_1x01_SMD_1x2mm
TP13 | TestPoint | 00_custom-footprints:SolderWirePad_1x01_SMD_1x2mm
TP14 | TestPoint | 00_custom-footprints:SolderWirePad_1x01_SMD_1x2mm
TP15 | TestPoint | 00_custom-footprints:SolderWirePad_1x01_SMD_1x2mm
TP16 | TestPoint | 00_custom-footprints:SolderWirePad_1x01_SMD_1x2mm
C1 | 100nF | Capacitor_SMD:C_0402_1005Metric
C2 | 1uF | Capacitor_SMD:C_0402_1005Metric
C3 | 22pF | Capacitor_SMD:C_0402_1005Metric
C4 | 22pF | Capacitor_SMD:C_0402_1005Metric
C5 | 100nF | Capacitor_SMD:C_0402_1005Metric
C6 | 1nF | Capacitor_SMD:C_0402_1005Metric
C7 | 100nF | Capacitor_SMD:C_0402_1005Metric
C8 | 1uF | Capacitor_SMD:C_0402_1005Metric
C9 | 1uF | Capacitor_SMD:C_0402_1005Metric
J1 | Conn_01x01_Pin | Connector_PinHeader_1.27mm:PinHeader_1x01_P1.27mm_Vertical
J7 | Conn_01x01_Pin | Connector_PinHeader_1.27mm:PinHeader_1x01_P1.27mm_Vertical
J9 | Conn_01x01_Pin | Connector_PinHeader_1.27mm:PinHeader_1x01_P1.27mm_Vertical
J10 | Conn_01x01_Pin | Connector_PinHeader_1.27mm:PinHeader_1x01_P1.27mm_Vertical
J11 | Conn_01x01_Pin | Connector_PinHeader_1.27mm:PinHeader_1x01_P1.27mm_Vertical
J12 | Conn_01x01_Pin | Connector_PinHeader_1.27mm:PinHeader_1x01_P1.27mm_Vertical
J13 | Conn_01x01_Pin | Connector_PinHeader_1.27mm:PinHeader_1x01_P1.27mm_Vertical
J14 | Conn_01x01_Pin | Connector_PinHeader_1.27mm:PinHeader_1x01_P1.27mm_Vertical
JP2 | SolderJumper_2_Bridged | Jumper:SolderJumper-2_P1.3mm_Bridged2Bar_RoundedPad1.0x1.5mm
R1 | 10K | Capacitor_SMD:C_0402_1005Metric
R2 | 10M | Capacitor_SMD:C_0402_1005Metric
U1 | ADS1293CISQE-NOPB | 00_Custom:ADS1293CISQE
U2 | AP2112K-3.3TRG1 | 00_lcsc:SOT-25-5_L2.9-W1.6-P0.95-LS2.8-BL |  | C51118
Y1 | Crystal | Crystal:Crystal_SMD_HC49-SD
C1 | 1uF | Capacitor_SMD:C_0402_1005Metric
C2 | 1uF | Capacitor_SMD:C_0402_1005Metric
C3 | 1uF | Capacitor_SMD:C_0402_1005Metric
C4 | 100nF | Capacitor_SMD:C_0402_1005Metric
C5 | 1uF | Capacitor_SMD:C_0402_1005Metric
C6 | 100nF | Capacitor_SMD:C_0402_1005Metric
C7 | 1.5nF | Capacitor_SMD:C_0402_1005Metric
C8 | 10uF | Capacitor_SMD:C_0402_1005Metric
C9 | 100nF | Capacitor_SMD:C_0402_1005Metric
C10 | 1nF | Capacitor_SMD:C_0402_1005Metric
C11 | 1uF | Capacitor_SMD:C_0402_1005Metric
C12 | 1uF | Capacitor_SMD:C_0402_1005Metric
C13 | 10uF | Capacitor_SMD:C_0402_1005Metric
C14 | 100nF | Capacitor_SMD:C_0402_1005Metric
C15 | 22uF | Capacitor_SMD:C_0402_1005Metric
J1 | Conn_01x01_Pin | 00_custom-footprints:PinHeader_1x01_P1.27mm_Vertical
J2 | Conn_01x01_Pin | 00_custom-footprints:PinHeader_1x01_P1.27mm_Vertical
J3 | Conn_01x01_Pin | 00_custom-footprints:PinHeader_1x01_P1.27mm_Vertical
J4 | Conn_01x01_Pin | 00_custom-footprints:PinHeader_1x01_P1.27mm_Vertical
J5 | Conn_01x01_Pin | 00_custom-footprints:PinHeader_1x01_P1.27mm_Vertical
J6 | Conn_01x01_Pin | 00_custom-footprints:PinHeader_1x01_P1.27mm_Vertical
J7 | Conn_01x01_Pin | 00_custom-footprints:PinHeader_1x01_P1.27mm_Vertical
J8 | Conn_01x01_Pin | 00_custom-footprints:PinHeader_1x01_P1.27mm_Vertical
J9 | Conn_01x01_Pin | 00_custom-footprints:SolderWirePad_1x01_SMD_1x2mm
J10 | Conn_01x01_Pin | 00_custom-footprints:SolderWirePad_1x01_SMD_1x2mm
J11 | Conn_01x01_Pin | 00_custom-footprints:SolderWirePad_1x01_SMD_1x2mm
J12 | Conn_01x01_Pin | 00_custom-footprints:SolderWirePad_1x01_SMD_1x2mm
J13 | Conn_01x01_Pin | 00_custom-footprints:SolderWirePad_1x01_SMD_1x2mm
J14 | Conn_01x01_Pin | 00_custom-footprints:SolderWirePad_1x01_SMD_1x2mm
J15 | Conn_01x01_Pin | 00_custom-footprints:SolderWirePad_1x01_SMD_1x2mm
J16 | Conn_01x01_Pin | 00_custom-footprints:SolderWirePad_1x01_SMD_1x2mm
J17 | Conn_01x01_Pin | 00_custom-footprints:SolderWirePad_1x01_SMD_1x2mm
J18 | Conn_01x01_Pin | 00_custom-footprints:SolderWirePad_1x01_SMD_1x2mm
J19 | Conn_01x01_Pin | 00_custom-footprints:SolderWirePad_1x01_SMD_1x2mm
J20 | Conn_01x01_Pin | 00_custom-footprints:SolderWirePad_1x01_SMD_1x2mm
J21 | Conn_01x01_Pin | 00_custom-footprints:SolderWirePad_1x01_SMD_1x2mm
J22 | Conn_01x01_Pin | 00_custom-footprints:SolderWirePad_1x01_SMD_1x2mm
J23 | Conn_01x01_Pin | 00_custom-footprints:SolderWirePad_1x01_SMD_1x2mm
J24 | Conn_01x01_Pin | 00_custom-footprints:SolderWirePad_1x01_SMD_1x2mm
J25 | Conn_01x01_Pin | 00_custom-footprints:PinHeader_1x01_P1.27mm_Vertical
J26 | Conn_01x01_Pin | 00_custom-footprints:PinHeader_1x01_P1.27mm_Vertical
R1 | 1M | Capacitor_SMD:C_0402_1005Metric
R2 | 10K | Capacitor_SMD:C_0402_1005Metric
SW1 | TS-1088R-02026 | 00_lcsc:SW-SMD_L3.9-W3.0-P4.45 |  | C455280
U1 | AP2112K-3.3TRG1 | 00_custom-footprints:SOT95P285X140-5N
U2 | ADS1298CZXGT | 00_lcsc:NFBGA-64_L8.0-W8.0-R8-C8-P0.80-TL |  | C882732
C1 | 10uF | Capacitor_SMD:C_0402_1005Metric
C2 | 100nF | Capacitor_SMD:C_0402_1005Metric
C3 | 10nF | Capacitor_SMD:C_0402_1005Metric
C4 | 100pF | Capacitor_SMD:C_0402_1005Metric
C5 | 100pF | Capacitor_SMD:C_0402_1005Metric
C6 | 1uF | Capacitor_SMD:C_0402_1005Metric
C7 | 1uF | Capacitor_SMD:C_0402_1005Metric
C8 | 1uF | Capacitor_SMD:C_0402_1005Metric
C9 | 100nF | Capacitor_SMD:C_0402_1005Metric
C10 | 1uF | Capacitor_SMD:C_0402_1005Metric
C11 | 1uF | Capacitor_SMD:C_0402_1005Metric
C12 | 100nF | Capacitor_SMD:C_0402_1005Metric
C13 | 1uF | Capacitor_SMD:C_0402_1005Metric
C14 | 100n | Capacitor_SMD:C_0402_1005Metric
C15 | 1u | Capacitor_SMD:C_0402_1005Metric
J1 | Conn_01x01_Pin | 00_custom-footprints:PinHeader_1x01_P1.27mm_Vertical
J2 | Conn_01x01_Pin | 00_custom-footprints:PinHeader_1x01_P1.27mm_Vertical
J3 | Conn_01x01_Pin | 00_custom-footprints:PinHeader_1x01_P1.27mm_Vertical
J4 | Conn_01x01_Pin | 00_custom-footprints:PinHeader_1x01_P1.27mm_Vertical
J5 | Conn_01x01_Pin | 00_custom-footprints:PinHeader_1x01_P1.27mm_Vertical
J6 | Conn_01x01_Pin | 00_custom-footprints:PinHeader_1x01_P1.27mm_Vertical
J7 | Conn_01x01_Pin | 00_custom-footprints:PinHeader_1x01_P1.27mm_Vertical
J8 | Conn_01x01_Pin | 00_custom-footprints:PinHeader_1x01_P1.27mm_Vertical
R1 | 2k | Resistor_SMD:R_0402_1005Metric
R2 | 10k | Resistor_SMD:R_0402_1005Metric
R3 | 330 | Resistor_SMD:R_0402_1005Metric
R4 | 4k | Resistor_SMD:R_0402_1005Metric
R5 | 4k | Resistor_SMD:R_0402_1005Metric
R6 | 10k | Resistor_SMD:R_0402_1005Metric
R7 | 10k | Resistor_SMD:R_0402_1005Metric
R8 | 100k | Resistor_SMD:R_0402_1005Metric
R9 | 1M | Resistor_SMD:R_0402_1005Metric
R10 | 1k | Resistor_SMD:R_0402_1005Metric
R11 | 100k | Resistor_SMD:R_0402_1005Metric
R12 | 1k | Resistor_SMD:R_0402_1005Metric
R13 | 0 | Resistor_SMD:R_0402_1005Metric
R14 | 0 | Resistor_SMD:R_0402_1005Metric
TP1 | TestPoint | 00_custom-footprints:TestPoint_Pad_D1.0mm
TP2 | TestPoint | 00_custom-footprints:TestPoint_Pad_D1.0mm
U1 | INA331IDGKR | 00_lcsc:VSSOP-8_L3.0-W3.0-P0.65-LS5.0-BL |  | C2863664
U2 | OPA333 | 00_lcsc:SOT-23-5_L2.9-W1.6-P0.95-LS2.8-BR |  | C3007938
U3 | AP2112K-3.3TRG1 | 00_lcsc:SOT-25-5_L2.9-W1.6-P0.95-LS2.8-BL |  | C51118
U4 | OPA333 | 00_lcsc:SOT-23-5_L2.9-W1.6-P0.95-LS2.8-BR |  | C3007938
U5 | CJ432 | 00_lcsc:SOT-23-3_L2.9-W1.3-P1.90-LS2.4-BR |  | C2910208
U6 | LIS3DHTR | 00_lcsc:LGA-16_L3.0-W3.0-P0.50-TL |  | C15134
C1 | 4.7uF | Capacitor_SMD:C_0402_1005Metric
J1 | Conn_01x01_Pin | 00_custom-footprints:PinHeader_1x01_P1.27mm_Vertical
J2 | Conn_01x01_Pin | 00_custom-footprints:PinHeader_1x01_P1.27mm_Vertical
J3 | Conn_01x01_Pin | 00_custom-footprints:PinHeader_1x01_P1.27mm_Vertical
J4 | Conn_01x01_Pin | 00_custom-footprints:PinHeader_1x01_P1.27mm_Vertical
J5 | Conn_01x01_Pin | 00_custom-footprints:PinHeader_1x01_P1.27mm_Vertical
J6 | Conn_01x01_Pin | 00_custom-footprints:PinHeader_1x01_P1.27mm_Vertical
J7 | Conn_01x01_Pin | 00_custom-footprints:PinHeader_1x01_P1.27mm_Vertical
J8 | Conn_01x01_Pin | 00_custom-footprints:PinHeader_1x01_P1.27mm_Vertical
J9 | Conn_01x01_Pin | 00_custom-footprints:TestPoint_Pad_D1.0mm
J10 | Conn_01x01_Pin | 00_custom-footprints:TestPoint_Pad_D1.0mm
J15 | Conn_01x01_Pin | 00_custom-footprints:PinHeader_1x01_P1.27mm_Vertical
J16 | Conn_01x01_Pin | 00_custom-footprints:PinHeader_1x01_P1.27mm_Vertical
J17 | Conn_01x01_Pin | 00_custom-footprints:PinHeader_1x01_P1.27mm_Vertical
J18 | Conn_01x01_Pin | 00_custom-footprints:TestPoint_Pad_D1.0mm
J19 | Conn_01x01_Pin | 00_custom-footprints:TestPoint_Pad_D1.0mm
J24 | Conn_01x01_Pin | 00_custom-footprints:PinHeader_1x01_P1.27mm_Vertical
Q1 | AO4882_C3040598 | 00_lcsc:SOIC-8_L4.9-W3.9-P1.27-LS6.0-BL |  | C3040598
Q2 | AO4882_C3040598 | 00_lcsc:SOIC-8_L4.9-W3.9-P1.27-LS6.0-BL |  | C3040598
R1 | 1k | Resistor_SMD:R_0402_1005Metric
R2 | 10K | Resistor_SMD:R_0402_1005Metric
R3 | 1k | Resistor_SMD:R_0402_1005Metric
R4 | 2k | Resistor_SMD:R_0402_1005Metric
R5 | 2k | Resistor_SMD:R_0402_1005Metric
R6 | 1k | Resistor_SMD:R_0402_1005Metric
R7 | 1k | Resistor_SMD:R_0402_1005Metric
R8 | 2k | Resistor_SMD:R_0402_1005Metric
R9 | 2k | Resistor_SMD:R_0402_1005Metric
SW1 | TS-1088R-02026 | 00_lcsc:SW-SMD_L3.9-W3.0-P4.45 |  | C455280
U1 | DS12W-MS | 00_lcsc:SOD-123FL_L2.7-W1.8-LS3.8-RD |  | C5120757
U2 | DS12W-MS | 00_lcsc:SOD-123FL_L2.7-W1.8-LS3.8-RD |  | C5120757
U3 | DS12W-MS | 00_lcsc:SOD-123FL_L2.7-W1.8-LS3.8-RD |  | C5120757
U4 | HC32L110C6UA-SFN20TR | 00_lcsc:WQFN-20_L3.0-W3.0-P0.40-BL-EP |  | C493490
U5 | DS12W-MS | 00_lcsc:SOD-123FL_L2.7-W1.8-LS3.8-RD |  | C5120757
C1 | 1uF | Capacitor_SMD:C_0402_1005Metric
C2 | 1uF | Capacitor_SMD:C_0402_1005Metric
C5 | 100nF | Capacitor_SMD:C_0402_1005Metric
J1 | Conn_01x01_Pin | 00_custom-footprints:PinHeader_1x01_P1.27mm_Vertical
J2 | Conn_01x01_Pin | 00_custom-footprints:PinHeader_1x01_P1.27mm_Vertical
J3 | Conn_01x01_Pin | 00_custom-footprints:PinHeader_1x01_P1.27mm_Vertical
J4 | Conn_01x01_Pin | 00_custom-footprints:PinHeader_1x01_P1.27mm_Vertical
J5 | Conn_01x01_Pin | 00_custom-footprints:PinHeader_1x01_P1.27mm_Vertical
J6 | Conn_01x01_Pin | 00_custom-footprints:PinHeader_1x01_P1.27mm_Vertical
J7 | Conn_01x01_Pin | 00_custom-footprints:PinHeader_1x01_P1.27mm_Vertical
J8 | Conn_01x01_Pin | 00_custom-footprints:PinHeader_1x01_P1.27mm_Vertical
J9 | Conn_01x01_Pin | 00_custom-footprints:PinHeader_1x01_P1.27mm_Vertical
J10 | Conn_01x01_Pin | 00_custom-footprints:PinHeader_1x01_P1.27mm_Vertical
J11 | Conn_01x01_Pin | 00_custom-footprints:PinHeader_1x01_P1.27mm_Vertical
J12 | Conn_01x01_Pin | 00_custom-footprints:PinHeader_1x01_P1.27mm_Vertical
J13 | Conn_01x01_Pin | 00_custom-footprints:PinHeader_1x01_P1.27mm_Vertical
J14 | Conn_01x01_Pin | 00_custom-footprints:PinHeader_1x01_P1.27mm_Vertical
J15 | Conn_01x01_Pin | 00_custom-footprints:PinHeader_1x01_P1.27mm_Vertical
J16 | Conn_01x01_Pin | 00_custom-footprints:PinHeader_1x01_P1.27mm_Vertical
J17 | Conn_01x01_Pin | 00_custom-footprints:PinHeader_1x01_P1.27mm_Vertical
J18 | Conn_01x01_Pin | 00_custom-footprints:PinHeader_1x01_P1.27mm_Vertical
R1 | 4.7k | Resistor_SMD:R_0402_1005Metric
R2 | 4.7k | Resistor_SMD:R_0402_1005Metric
R3 | 4.7k | Resistor_SMD:R_0402_1005Metric
R4 | 4.7k | Resistor_SMD:R_0402_1005Metric
R5 | 4.7k | Resistor_SMD:R_0402_1005Metric
R6 | 4.7k | Resistor_SMD:R_0402_1005Metric
R7 | 4.7k | Resistor_SMD:R_0402_1005Metric
R8 | 4.7k | Resistor_SMD:R_0402_1005Metric
U1 | MCP1700T-1802E/TT | 00_lcsc:SOT-23-3_L2.9-W1.3-P1.90-LS2.4-BR |  | C150796
U3 | BSS138BKS | 00_lcsc:SOT-363_L2.1-W1.3-P0.65-LS2.3-BL |  | C5224290
U4 | ICM-20948 | Package_DFN_QFN:QFN-24-1EP_3x3mm_P0.4mm_EP1.75x1.6mm |  | C726001
U5 | BSS138BKS | 00_lcsc:SOT-363_L2.1-W1.3-P0.65-LS2.3-BL |  | C5224290
J1 | jack2.5_PJ-210B | 00_custom-footprints:Jack_Socket_PJ-210B
J2 | jack2.5_PJ-210B | 00_custom-footprints:Jack_Socket_PJ-210B
J3 | jack2.5_PJ-210B | 00_custom-footprints:Jack_Socket_PJ-210B
J4 | jack2.5_PJ-210B | 00_custom-footprints:Jack_Socket_PJ-210B
J5 | jack2.5_PJ-210B | 00_custom-footprints:Jack_Socket_PJ-210B
J6 | jack2.5_PJ-210B | 00_custom-footprints:Jack_Socket_PJ-210B
J7 | jack2.5_PJ-210B | 00_custom-footprints:Jack_Socket_PJ-210B
J8 | jack2.5_PJ-210B | 00_custom-footprints:Jack_Socket_PJ-210B
J9 | jack2.5_PJ-210B | 00_custom-footprints:Jack_Socket_PJ-210B
J10 | Conn_01x01_Pin | Connector_PinHeader_2.54mm:PinHeader_1x01_P2.54mm_Vertical
J11 | Conn_01x01_Pin | Connector_PinHeader_2.54mm:PinHeader_1x01_P2.54mm_Vertical
J12 | Conn_01x01_Pin | 00_custom-footprints:Pin_D1.2mm_pogo
J13 | Conn_01x01_Pin | 00_custom-footprints:Pin_D1.2mm_pogo
J14 | Conn_01x01_Pin | 00_custom-footprints:Pin_D1.2mm_pogo
J15 | Conn_01x01_Pin | 00_custom-footprints:Pin_D1.2mm_pogo
J16 | Conn_01x01_Pin | 00_custom-footprints:Pin_D1.2mm_pogo
J17 | Conn_01x01_Pin | 00_custom-footprints:Pin_D1.2mm_pogo
J18 | Conn_01x01_Pin | 00_custom-footprints:Pin_D1.2mm_pogo
J19 | Conn_01x01_Pin | 00_custom-footprints:Pin_D1.2mm_pogo
J20 | Conn_01x01_Pin | 00_custom-footprints:Pin_D1.2mm_pogo
J21 | Conn_01x01_Pin | 00_custom-footprints:Pin_D1.2mm_pogo
J22 | Conn_01x01_Pin | 00_custom-footprints:Pin_D1.2mm_pogo
J23 | Conn_01x01_Pin | 00_custom-footprints:Pin_D1.2mm_pogo
J24 | Conn_01x01_Pin | 00_custom-footprints:Pin_D1.2mm_pogo
J25 | Conn_01x01_Pin | 00_custom-footprints:Pin_D1.2mm_pogo
J26 | Conn_01x01_Pin | 00_custom-footprints:Pin_D1.2mm_pogo
J27 | Conn_01x01_Pin | 00_custom-footprints:Pin_D1.2mm_pogo
C3 | 2.2uF | Capacitor_SMD:C_0402_1005Metric
C4 | 22uF | Capacitor_SMD:C_0402_1005Metric
C5 | 22nF | Capacitor_SMD:C_0402_1005Metric
C6 | 10nF | Capacitor_SMD:C_0402_1005Metric
C7 | 2.2uF - 16V ceramic X7R | Capacitor_SMD:C_0603_1608Metric
J1 | Conn_01x01_Pin | 00_custom-footprints:PinHeader_1x01_P1.27mm_Vertical
J2 | Conn_01x01_Pin | 00_custom-footprints:PinHeader_1x01_P1.27mm_Vertical
J3 | Conn_01x01_Pin | 00_custom-footprints:PinHeader_1x01_P1.27mm_Vertical
J4 | Conn_01x01_Pin | 00_custom-footprints:PinHeader_1x01_P1.27mm_Vertical
J5 | Conn_01x01_Pin | 00_custom-footprints:PinHeader_1x01_P1.27mm_Vertical
J6 | Conn_01x01_Pin | 00_custom-footprints:PinHeader_1x01_P1.27mm_Vertical
J7 | Conn_01x01_Pin | 00_custom-footprints:PinHeader_1x01_P1.27mm_Vertical
J8 | Conn_01x01_Pin | 00_custom-footprints:PinHeader_1x01_P1.27mm_Vertical
J9 | Conn_01x01_Pin | 00_custom-footprints:PinHeader_1x01_P1.27mm_Vertical
J10 | Conn_01x01_Pin | 00_custom-footprints:PinHeader_1x01_P1.27mm_Vertical
J11 | Conn_01x01_Pin | 00_custom-footprints:PinHeader_1x01_P1.27mm_Vertical
J12 | Conn_01x01_Pin | 00_custom-footprints:PinHeader_1x01_P1.27mm_Vertical
J13 | Conn_01x01_Pin | 00_custom-footprints:PinHeader_1x01_P1.27mm_Vertical
J14 | Conn_01x01_Pin | 00_custom-footprints:PinHeader_1x01_P1.27mm_Vertical
J15 | Conn_01x01_Pin | 00_custom-footprints:PinHeader_1x01_P1.27mm_Vertical
J16 | Conn_01x01_Pin | 00_custom-footprints:PinHeader_1x01_P1.27mm_Vertical
J17 | Conn_01x01_Pin | 00_custom-footprints:PinHeader_1x01_P1.27mm_Vertical
J18 | Conn_01x01_Pin | 00_custom-footprints:PinHeader_1x01_P1.27mm_Vertical
J19 | Conn_01x01_Pin | 00_custom-footprints:PinHeader_1x01_P1.27mm_Vertical
J20 | Conn_01x01_Pin | 00_custom-footprints:PinHeader_1x01_P1.27mm_Vertical
J21 | Conn_01x01_Pin | 00_custom-footprints:PinHeader_1x01_P1.27mm_Vertical
J22 | Conn_01x01_Pin | 00_custom-footprints:PinHeader_1x01_P1.27mm_Vertical
J23 | Conn_01x01_Pin | 00_custom-footprints:PinHeader_1x01_P1.27mm_Vertical
J24 | Conn_01x01_Pin | 00_custom-footprints:PinHeader_1x01_P1.27mm_Vertical
L1 | FNR5040S330MT | 00_lcsc:IND-SMD_L5.0-W5.0_FNR50XXS |  | C167973
L2 | FNR5040S330MT | 00_lcsc:IND-SMD_L5.0-W5.0_FNR50XXS |  | C167973
R1 | 0.33 | Resistor_SMD:R_1206_3216Metric
R2 | 0.33 | Resistor_SMD:R_1206_3216Metric
R3 | 1k | Resistor_SMD:R_0402_1005Metric
R4 | 47k | Resistor_SMD:R_0402_1005Metric
R5 | 18k | Resistor_SMD:R_0402_1005Metric
R6 | 1k | Resistor_SMD:R_0402_1005Metric
R7 | 1k | Resistor_SMD:R_0402_1005Metric
U3 | STSPIN240 | 00_lcsc:QFN-16_L3.0-W3.0-P0.50-BL-EP1.7 |  | C962258

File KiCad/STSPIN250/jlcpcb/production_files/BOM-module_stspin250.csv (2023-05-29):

Comment | Designator | Footprint | LCSC
smd_insert | I8 | insert_1.2mm
smd_insert | I7 | insert_1.2mm
smd_insert | I6 | insert_1.2mm
smd_insert | I5 | insert_1.2mm
Conn_01x01_Pin | J9 | Pin_D1.2mm_pogo
Conn_01x01_Pin | J11 | Pin_D1.2mm_pogo
Conn_01x01_Pin | J10 | Pin_D1.2mm_pogo
Conn_01x01_Pin | J8 | Pin_D1.2mm_pogo
Conn_01x01_Pin | J7 | Pin_D1.2mm_pogo
Conn_01x01_Pin | J6 | Pin_D1.2mm_pogo
Conn_01x01_Pin | J5 | Pin_D1.2mm_pogo
Conn_01x02_Pin | J4 | PinHeader_1x02_P1.27mm_Vertical
Conn_01x04_Pin | J3 | PinHeader_1x04_P1.27mm_Vertical
Conn_01x02_Pin | J2 | PinHeader_1x02_P1.27mm_Vertical
Conn_01x02_Pin | J1 | PinHeader_1x02_P1.27mm_Vertical
STSPIN240 | U1 | VQFN-16-1EP_3x3mm_P0.5mm_EP1.8x1.8mm
R | R7 | R_0402_1005Metric
R | R6 | R_0402_1005Metric
R | R5 | R_0402_1005Metric
R | R4 | R_0402_1005Metric
R | R3 | R_0402_1005Metric
150 | R2 | R_0402_1005Metric
R | R1 | R_0402_1005Metric
SolderJumper_2_Open | JP4 | SolderJumper-2_P1.3mm_Open_RoundedPad1.0x1.5mm
SolderJumper_2_Open | JP3 | SolderJumper-2_P1.3mm_Open_RoundedPad1.0x1.5mm
SolderJumper_2_Open | JP2 | SolderJumper-2_P1.3mm_Open_RoundedPad1.0x1.5mm
SolderJumper_2_Open | JP1 | SolderJumper-2_P1.3mm_Open_RoundedPad1.0x1.5mm
C | C6 | C_0402_1005Metric
C | C5 | C_0402_1005Metric
C | C4 | C_0402_1005Metric
C | C3 | C_0402_1005Metric
C | C2 | C_0402_1005Metric
C | C1 | C_0402_1005Metric
TP_AUX2 | TP12 | TestPoint_Pad_D1.0mm
TP_SDA | TP10 | TestPoint_Pad_D1.0mm
smd_insert | I4 | insert_1.2mm
smd_insert | I2 | insert_1.2mm
smd_insert | I3 | insert_1.2mm
smd_insert | I1 | insert_1.2mm

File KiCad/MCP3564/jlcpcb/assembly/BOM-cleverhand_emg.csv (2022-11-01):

Comment | Designator | Footprint | LCSC
MCP3564RT-ENC | U1 | MCP3564RT-E&slash_NC | C625488
1515 | D4 | neopixel_1515
1515 | D3 | neopixel_1515
1515 | D2 | neopixel_1515
1515 | D1 | neopixel_1515
10R | R6 | R_0402_1005Metric
10R | R7 | R_0402_1005Metric
COM_OUT | J2 | XF2J-1824-12A
COM_IN | J1 | XF2J-1824-12A
10R | R1 | R_0402_1005Metric
100nF | C2 | C_0402_1005Metric
1-4_neo_bridge | JP1 | SolderJumper-3_P1.3mm_Bridged12_RoundedPad1.0x1.5mm_NumberLabels
SN74LVC86ARGYR | U2 | SN74LVC86ARGYR
10R | R4 | R_0402_1005Metric
10uF | C3 | C_0402_1005Metric
100nF | C1 | C_0402_1005Metric
SN74ALVC08RGYR | U4 | SN74ALVC08RGYR
10R | R8 | R_0402_1005Metric
SN74LVC1G132DCKR | U5 | SN74LVC1G132DCKR
10R | R3 | R_0402_1005Metric
10R | R5 | R_0402_1005Metric
10R | R2 | R_0402_1005Metric
TestPoint_Probe | TP4 | TestPoint_Pad_D1.0mm
TestPoint_Probe | TP2 | TestPoint_Pad_D1.0mm
TestPoint_Probe | TP3 | TestPoint_Pad_D1.0mm
TestPoint_Probe | TP1 | TestPoint_Pad_D1.0mm

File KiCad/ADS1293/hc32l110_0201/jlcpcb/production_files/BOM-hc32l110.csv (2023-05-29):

Comment | Designator | Footprint | LCSC
10K | R1 | C_0201_0603Metric | C106225
ADS1293CISQE-NOPB | U1 | ADS1293CISQE | C181260
4.096MHz | XTAL1 | SMD3225-4P | C255991
22pF | C1,C2 | C_0201_0603Metric | C272881
10M | R2 | C_0201_0603Metric | C320452
51 | R4 | C_0201_0603Metric | C320945
4.7uF | C7 | C_0201_0603Metric | C335103
XF2J-1824-12A | J1,J2 | XF2J-1824-12A | C397324
HC32L110C6UA | U2 | QFN-20-1EP_3x3mm_P0.4mm_EP1.4x1.4mm | C493490
1nF | C4 | C_0201_0603Metric | C526941
1uF | C6 | C_0201_0603Metric | C53067
100nF | C3,C5,C8 | C_0201_0603Metric | C66938
WS2812-2020 | LED1 | WS2812-2020 | C965555

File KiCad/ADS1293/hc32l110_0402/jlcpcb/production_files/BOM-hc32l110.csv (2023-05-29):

Comment | Designator | Footprint | LCSC
1nF | C4 | C_0402_1005Metric | C1523
100nF | C3,C5,C7 | C_0402_1005Metric | C1525
ADS1293CISQE-NOPB | U1 | ADS1293CISQE | C181260
4.7uF | C8 | C_0402_1005Metric | C23733
51 | R3 | C_0402_1005Metric | C25125
10K | R1 | C_0402_1005Metric | C25744
10M | R2 | C_0402_1005Metric | C26082
4.096MHz | XTAL1 | SMD3225-4P | C387328
XF2J-1824-12A | J1,J2 | XF2J-1824-12A | C397324
HC32L110C6UA | U2 | QFN-20-1EP_3x3mm_P0.4mm_EP1.4x1.4mm | C493490
1uF | C6 | C_0402_1005Metric | C52923
WS2812-2020 | LED1 | WS2812-2020

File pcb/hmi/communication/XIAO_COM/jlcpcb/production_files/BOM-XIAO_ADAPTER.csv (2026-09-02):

Comment | Designator | Footprint | LCSC | Quantity
ZX-PZ1.0-2-13PWZ | H1 | HDR-SMD_ZX-PZ1.0-2-13PWZ | C41370707 | 1
XIAO-ESP32-C3-DIP | U1 | XIAO-ESP32C6-DIP |  | 1

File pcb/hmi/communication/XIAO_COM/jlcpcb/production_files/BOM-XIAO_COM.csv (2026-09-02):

Comment | Designator | Footprint | LCSC | Quantity
100nF | C11,C4 | C_0402_1005Metric | C1525 | 2
10k | R10,R17 | R_0201_0603Metric | C25744 | 2
1uF | C28 | C_0201_0603Metric | C52923 | 1
BQ27421YZFR-G1A | U6 | DSBGA-9_L1.5-W1.5-R3-C3-P0.50-BL | C139621 | 1
ICM-42670-L | U2 | LGA-14_L3.0-W2.5-P0.50-TL_QMI8658A | C49073546 | 1
WS2812 | U10 | LED-SMD_4P-L2.0-W2.0-TL_WS2812B-2020 | C2976072 | 1
XIAO-ESP32-S3-DIP | U1 | XIAO-ESP32S3-DIP |  | 1
Conn_01x02_Pin | J2 | PinHeader_1x02_P1.27mm_Vertical |  | 1
Conn_01x02_Pin | J1 | PinHeader_1x02_P1.27mm_Vertical |  | 1
Conn_01x10_Pin | J4 | PinHeader_1x10_P1.27mm_Vertical |  | 1

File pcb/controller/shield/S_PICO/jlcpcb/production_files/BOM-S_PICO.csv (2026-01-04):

Comment | Designator | Footprint | LCSC | Quantity
2k | R1,R2 | R_0402_1005Metric_Pad0.72x0.64mm_HandSolder | C4109 | 2
FPC-05F-18PH20 | FPC1 | FPC-SMD_18P-P0.50_X05C2018TZ | C397324 | 1

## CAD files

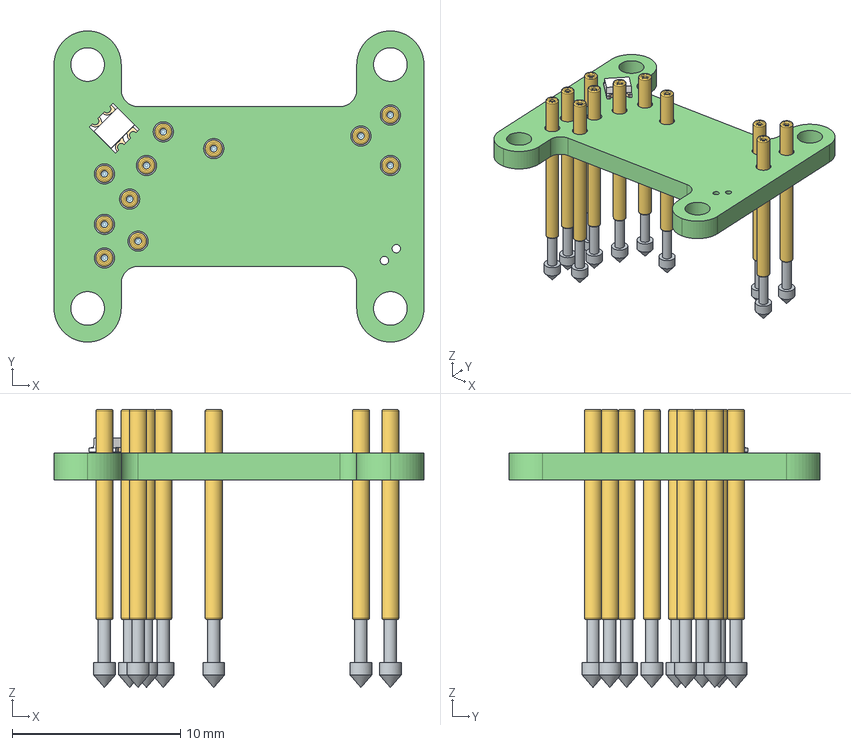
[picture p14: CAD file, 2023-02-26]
KiCad/ADS1293/hc32l110_0201/ext_board_drv2605/ext_board_drv2605.step
22.0 x 18.5 x 16.5 mm
ext_board_drv2605 PCB

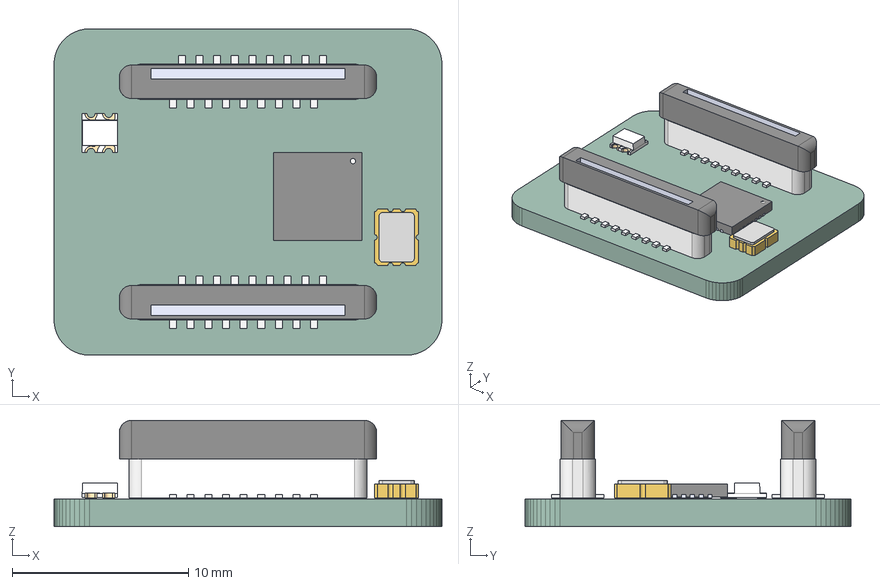
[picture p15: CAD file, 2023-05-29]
KiCad/ADS1293/hc32l110_0201/hc32l110.step
22.0 x 18.5 x 6.03 mm
PCB

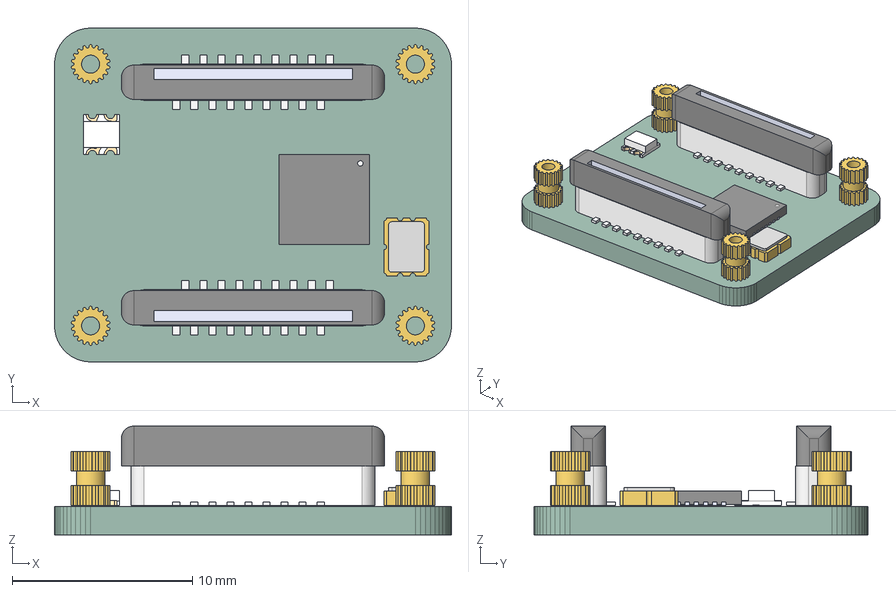
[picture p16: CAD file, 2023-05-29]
KiCad/ADS1293/logicGate_hc32l110/hc32l110.step
22.0 x 18.5 x 6.03 mm
hc32l110 PCB

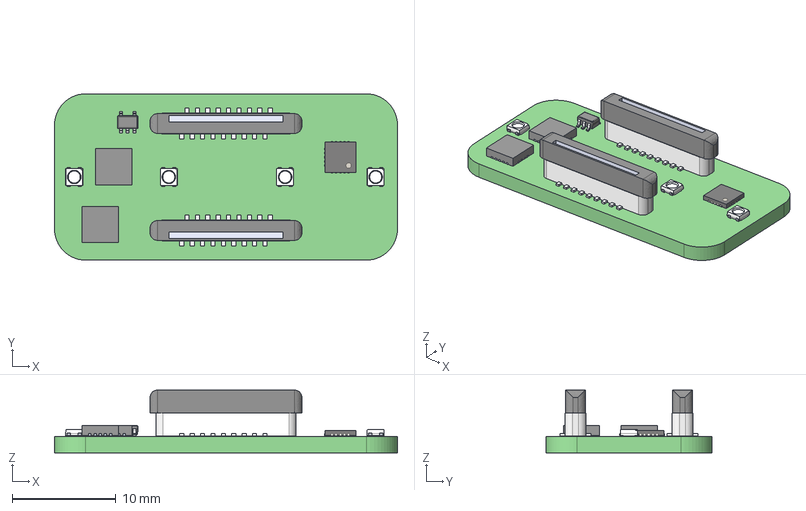
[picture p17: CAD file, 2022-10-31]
KiCad/MCP3564/cleverhand_emg.step
33.0 x 16.0 x 6.05 mm
cleverhand_emg PCB

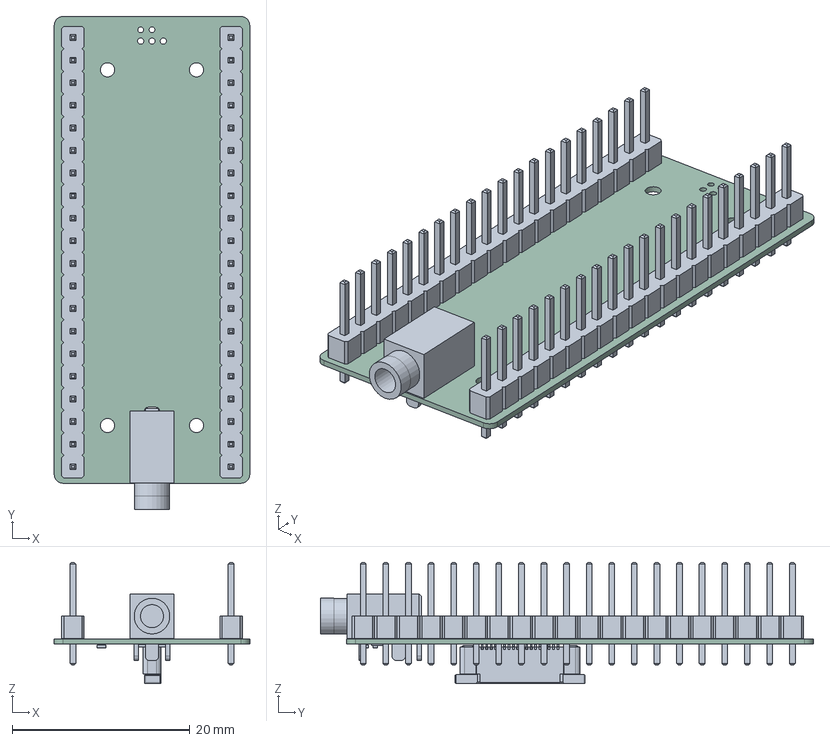
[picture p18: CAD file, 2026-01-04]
pcb/controller/shield/S_PICO/plots/S_PICO.step
22.0 x 55.4 x 13.6 mm
jack2.5_PJ-210B
PinHeader_1x20_P2.54mm_Vertical x 2
FPC-SMD_18P-P0.50_L14.6-W4.4-H2.0-X05C2018TZ
R_0402_1005Metric x 2
S_PICO_PCB

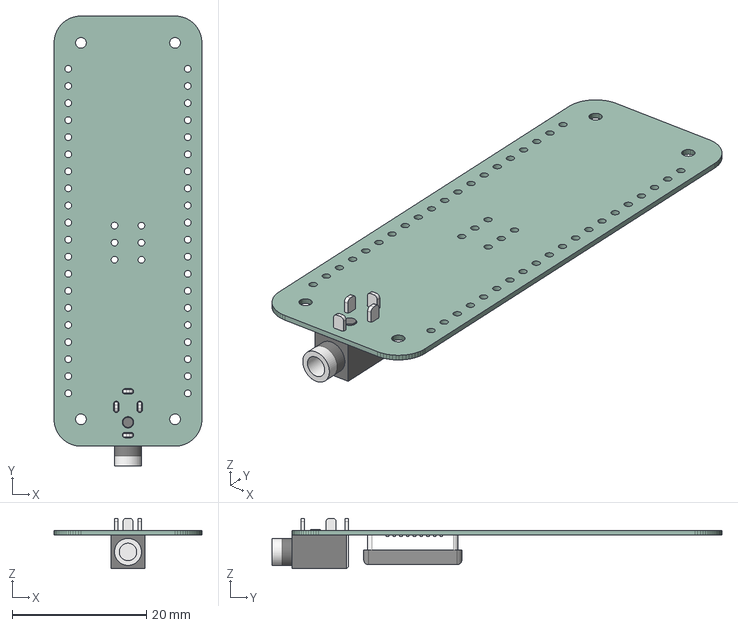
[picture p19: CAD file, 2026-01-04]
pcb/controller/shield/S_PICO/S_PICO.step
22.0 x 66.9 x 7.50 mm
S_PICO PCB

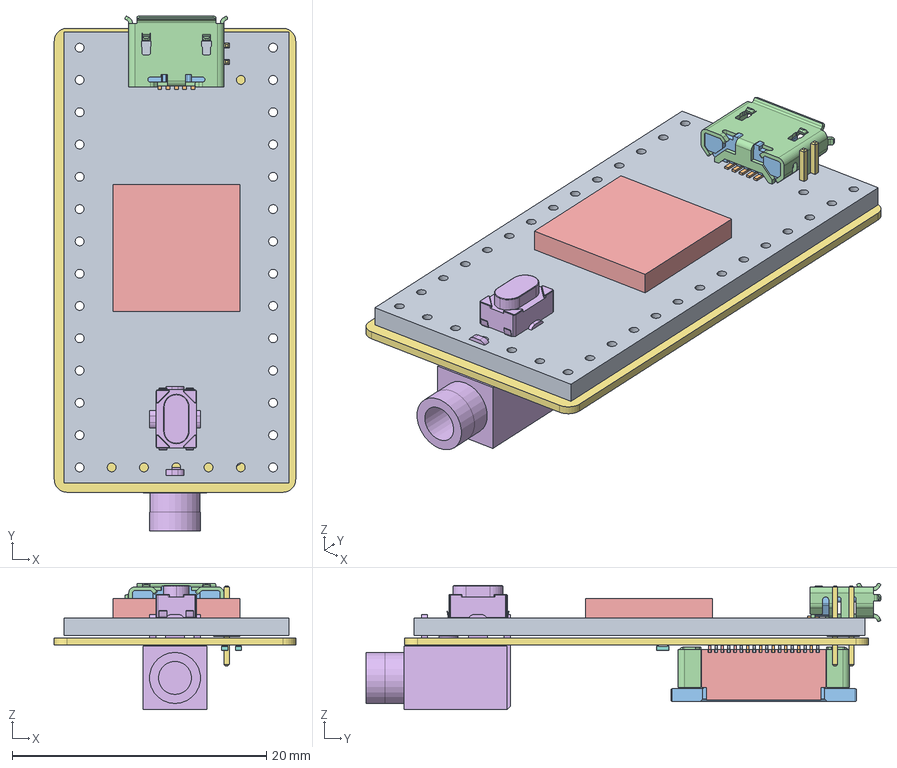
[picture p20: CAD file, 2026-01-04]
pcb/controller/shield/S_TEENSY4/plots/S_TEENSY4.step
19.0 x 40.5 x 9.95 mm
Teensy_4.0_PCB
Micro USB-B Female 5Pin SMD
NXP iMXRT1062
SKRPACE010 v4
PinHeader_1x02_P1.27mm_Vertical
R_0402_1005Metric x 2
FPC-SMD_18P-P0.50_L14.6-W4.4-H2.0-X05C2018TZ
jack2.5_PJ-210B
S_TEENSY4_PCB

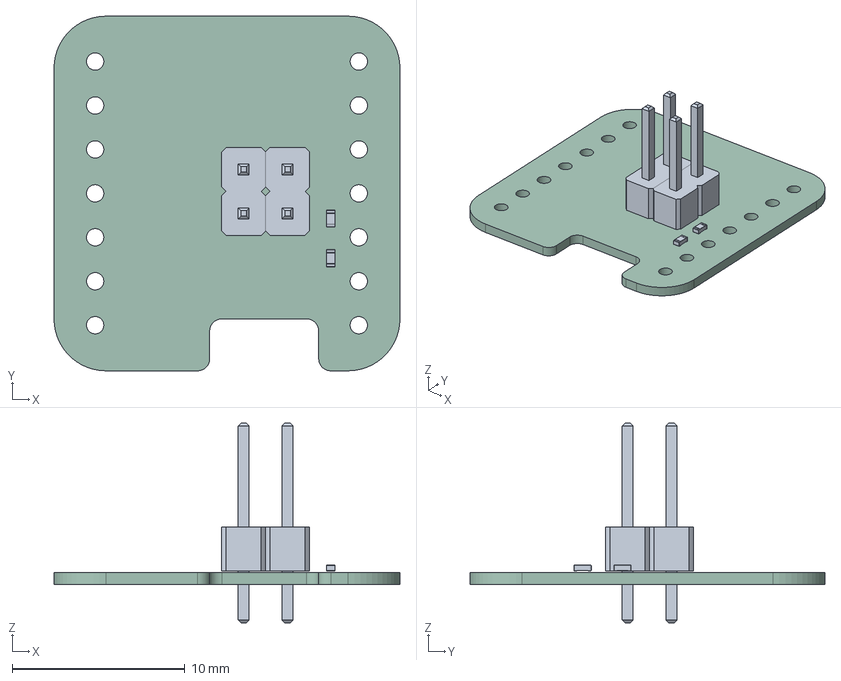
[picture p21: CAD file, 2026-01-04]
pcb/controller/shield/S_XIAO/plots/S_XIAO.step
20.0 x 20.5 x 11.5 mm
R_0402_1005Metric x 2
FPC-SMD_18P-P0.50_FPC-05F-18PH20
PinHeader_1x02_P2.54mm_Vertical x 2
S_XIAO_PCB

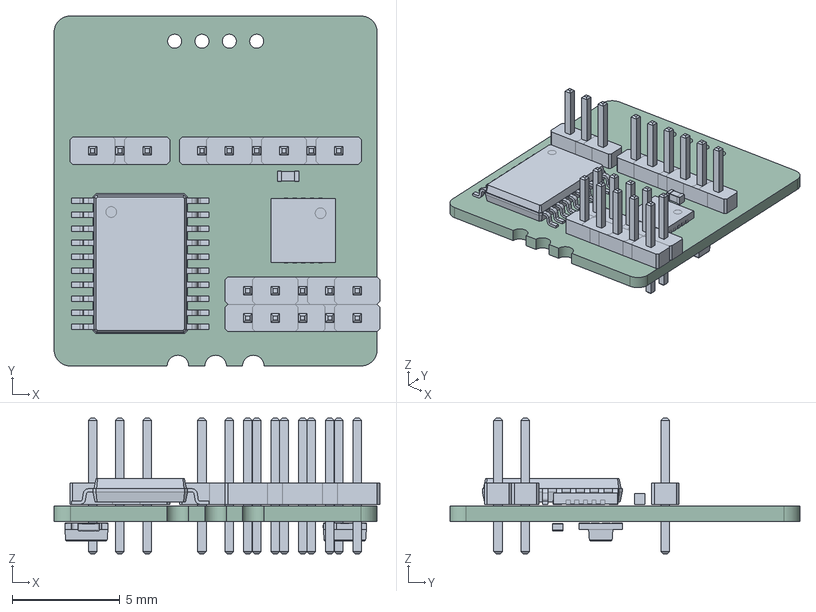
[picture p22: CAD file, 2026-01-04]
pcb/hmi/communication/COM_MOD/plots/COM_MOD.step
15.1 x 16.3 x 6.30 mm
PinHeader_1x01_P1.27mm_Vertical x 19
UQFN-20-1EP_3x3mm_P0.4mm_EP1.85x1.85mm
C_0402_1005Metric
FPC-SMD_18P-P0.50_FPC-05F-18PH20 x 2
TSSOP-20_4.4x6.5mm_P0.65mm
LED-SMD_4P-L2.0-W2.0-H0.8-TL_WS2812B-2020 x 2
R_0402_1005Metric
SW-SMD_L3.9-W2.9-H2.0-LS4.8
COM_MOD_PCB

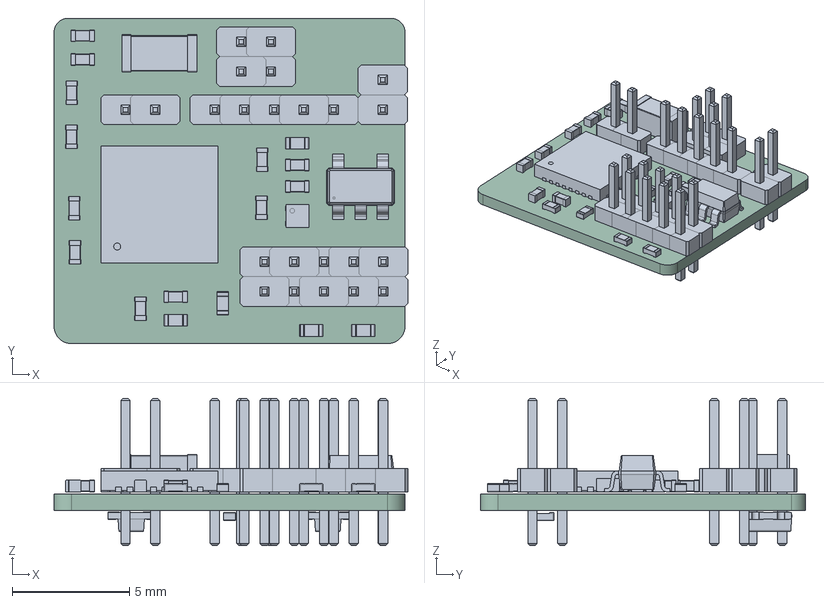
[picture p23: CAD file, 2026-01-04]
pcb/hmi/communication/MONO_CTRL/plots/MONO_CTRL.step
15.1 x 13.9 x 6.30 mm
PinHeader_1x01_P1.27mm_Vertical x 23
R_0402_1005Metric x 6
ESP32-C3FH4
C_0402_1005Metric x 11
SOT-23-5
L_0402_1005Metric
UDFN-4-1EP_1x1mm_P0.65mm_EP0.48x0.48mm
C_1206_3216Metric
LED-SMD_4P-L2.0-W2.0-H0.8-TL_WS2812B-2020 x 2
SW-SMD_L3.9-W2.9-H2.0-LS4.8 x 2
MONO_CTRL_PCB

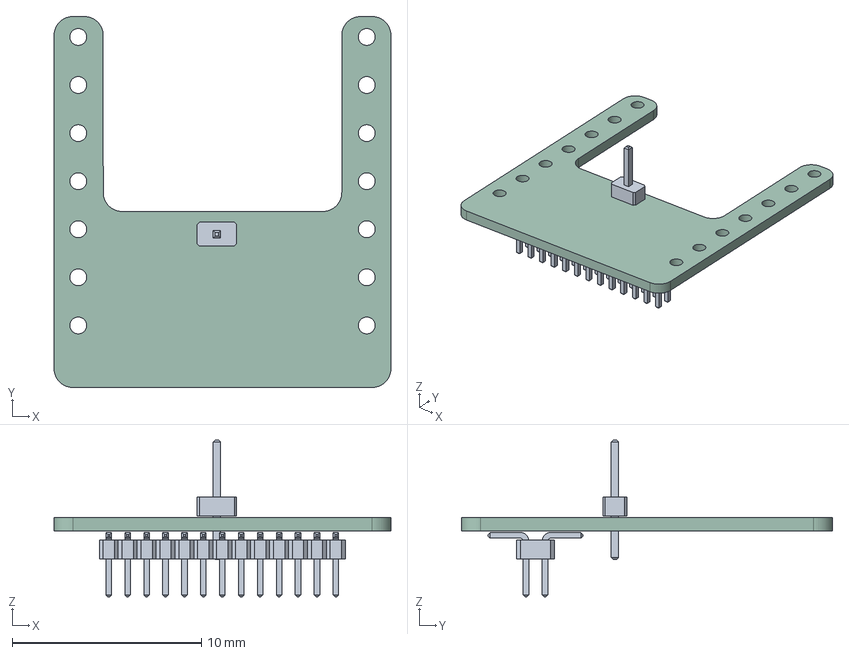
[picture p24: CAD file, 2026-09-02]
pcb/hmi/communication/XIAO_COM/plots/XIAO_COM.step
17.8 x 19.6 x 8.28 mm
PinHeader_1x01_P1.27mm_Vertical
XIAO_ADAPTER_PCB

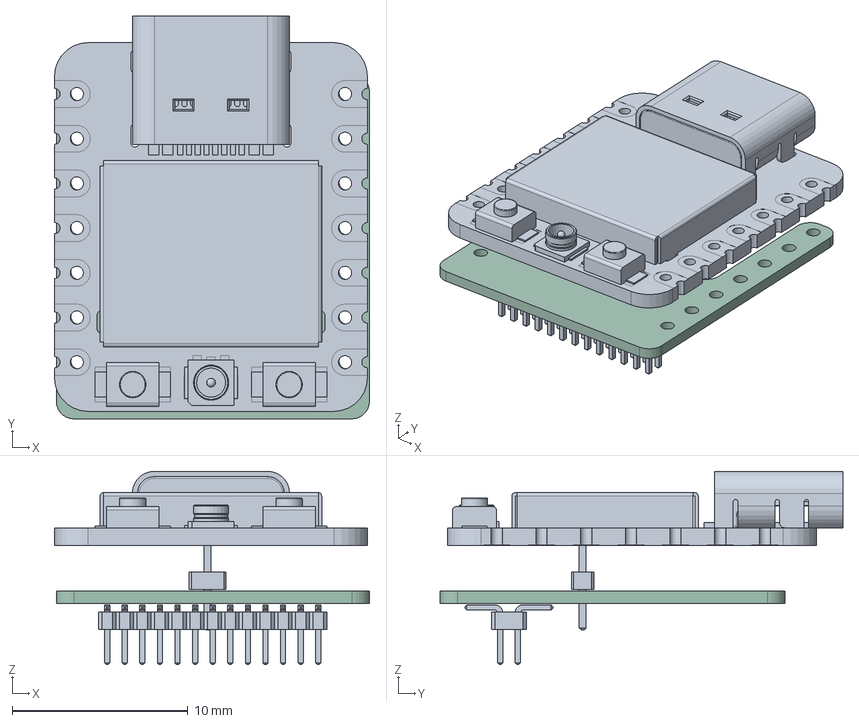
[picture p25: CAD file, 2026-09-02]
pcb/hmi/communication/XIAO_COM/XIAO_COM.step
17.9 x 22.9 x 11.0 mm
PinHeader_1x01_P1.27mm_Vertical
BOSS-EXTRUDE14_8_
BOSS-EXTRUDE7_4_
BOSS-EXTRUDE7_3_
BOSS-EXTRUDE14_4_
BOSS-EXTRUDE14_2_
BOSS-EXTRUDE14_11_
BOSS-EXTRUDE7_7_
BOSS-EXTRUDE14_9_
BOSS-EXTRUDE14_3_
BOSS-EXTRUDE14_7_
MIRROR2
BOSS-EXTRUDE14_5_
BOSS-EXTRUDE14_12_
BOSS-EXTRUDE7_8_
BOSS-EXTRUDE7_1_
BOSS-EXTRUDE14_10_
BOSS-EXTRUDE7_9_
BOSS-EXTRUDE14_6_
BOSS-EXTRUDE14_1_
BOSS-EXTRUDE7_6_
BOSS-EXTRUDE7_2_
CUT-EXTRUDE5
BOSS-EXTRUDE7_5_
U.FL Connector v1
Button (1) x 2
Shield
XIAO_ADAPTER_PCB

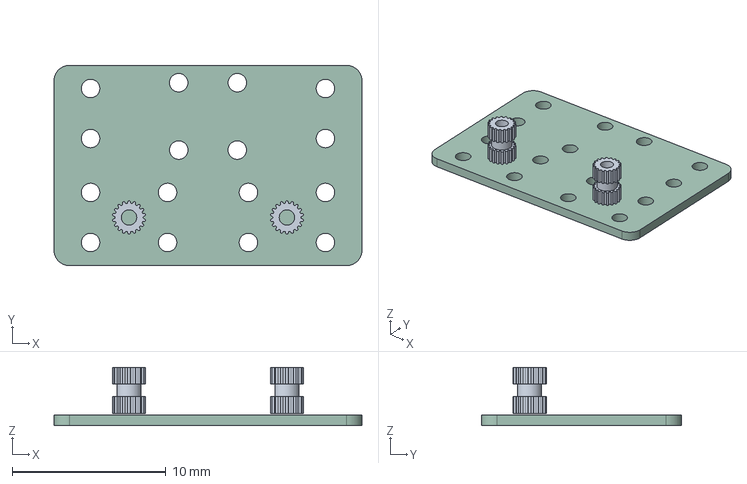
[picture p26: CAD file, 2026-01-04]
pcb/hmi/interface/DRY_ELEC_16CH/plots/DRY_ELEC_16CH.step
20.0 x 13.0 x 3.79 mm
insert_2mm x 2
DRY_ELEC_16CH_PCB

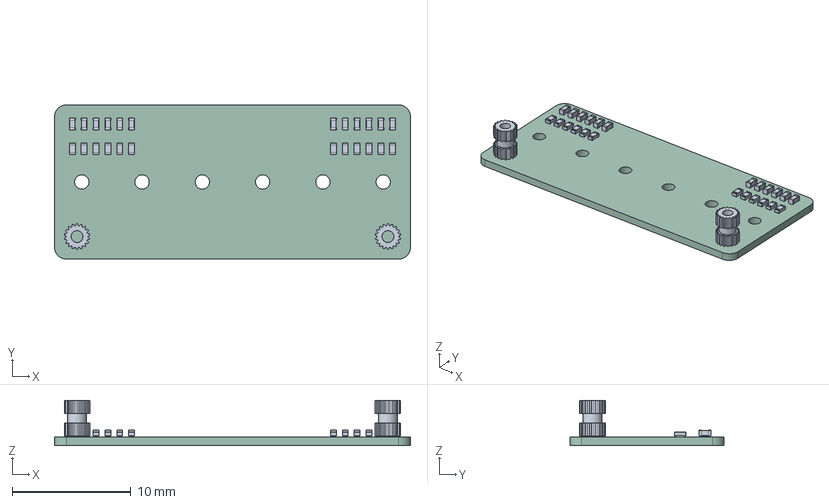
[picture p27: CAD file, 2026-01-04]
pcb/hmi/interface/DRY_ELEC_6CH/plots/DRY_ELEC_6CH.step
30.0 x 13.0 x 3.79 mm
C_0402_1005Metric x 12
insert_2mm x 2
R_0402_1005Metric x 12
DRY_ELEC_6CH_PCB

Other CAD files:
pcb/hmi/interface/DRY_ELEC_6CH_MID/plots/DRY_ELEC_6CH_MID.step
pcb/hmi/interface/DRY_ELEC_6CH_THIN/plots/DRY_ELEC_6CH_THIN.step
pcb/hmi/submodule/feedback/FES_AO4882/plots/FES_AO4882.step
pcb/hmi/submodule/feedback/VIB_STSPIN240/plots/VIB_STSPIN240.step
3d_model/modules/combined.blend
docs/img/bracelet_one.blend
docs/img/moduleAssempbly.blend
pcb/.archived/ADS1293/hc32l110_0201/assembly.blend
pcb/.archived/ADS1293/hc32l110_0402/assembly.blend
pcb/controller/shield/S_PICO/plots/S_PICO.stl
pcb/controller/shield/S_TEENSY4/plots/S_TEENSY4.stl
pcb/controller/shield/S_XIAO/plots/S_XIAO.stl
pcb/hmi/communication/COM_MOD/plots/COM_MOD.stl
pcb/hmi/communication/MONO_CTRL/plots/MONO_CTRL.stl
pcb/hmi/communication/XIAO_COM/plots/XIAO_COM.stl
pcb/hmi/interface/DRY_ELEC_16CH/plots/DRY_ELEC_16CH.stl
pcb/hmi/interface/DRY_ELEC_6CH/plots/DRY_ELEC_6CH.stl
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

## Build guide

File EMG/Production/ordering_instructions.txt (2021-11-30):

panel size, 87x90mm
PCB thickness, 1.6mm
number of layers, 4
soldermask color, Unknown
silkscreen color, White
oz copper, 1oz
finish, HASL lead free
stencils, none
pcs per panel, 16
min trace width, 0.1000mm / 0.0039in
min drill size, 0.2000mm / 0.0079in
filename to layer stackup 1/2/3/4: GTL, GL2, GL3, GBL

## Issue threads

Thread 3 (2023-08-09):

How to connect the sensor to arduino or raspberry pi

jomfawad, 2023-08-09:
I have question can i control this emg sensor directly with  arduino or raspberry pi without using the spi bus in this schematic? and if it works and i want to connect the sensor to the arduino how do i connect it? because there isnt wires, if you could please explain how to connect it step by step to arduino and which code to use to be able to read signals from the sensor and see them in arduino ide serial monitor? Thank you in advance

Aightech, 2023-09-08:
Yes you can connect my little modules on an Arduino.
Here is the repo for the interfacing code https://github.com/Aightech/CleverHand-interface more specifically the arduino code :https://github.com/Aightech/CleverHand-interface/tree/main/src/uctrl_master

I will make some videos explaining the project and how to make it yourself by the end of September ;)

Closed 2023-09-08.

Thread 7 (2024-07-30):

Part does not match pads on CONTROLLER_teensy4

jcykao, 2024-07-30:
The part FPC-05F-18PH20 does not match the pads on the CONTROLLER_teensy4 PCB.

Aightech, 2024-07-30:
Thank you, I fixed it with commit [0dbc59b](https://github.com/Aightech/CleverHand-hardware/commit/0dbc59be27e85e61426490ae17383ddd2622bea1)

Closed 2024-07-30.

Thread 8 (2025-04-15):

Issue connecting modules

howardshu, 2025-04-15:
I am looking to combine a DRY Electrode with a DAQ ADS1293 and communication module, but it appears that my components are slightly different from the 3D models in the repository. Photos of my ADS1293 and communication module are below, and the last photo shows my trouble in combining them. How do I arrange them like how they are shown in the repository? ([back view](https://github.com/Aightech/CleverHand-hardware/blob/f293d6ac1fdfa5e2498e7c9aad0dfd6b28f17918/3d_model/modules/render/combination_1_back.png), [front view](https://github.com/Aightech/CleverHand-hardware/blob/f293d6ac1fdfa5e2498e7c9aad0dfd6b28f17918/3d_model/modules/render/combination_1_front.png))

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

Aightech, 2025-04-17:
Hi @howardshu, you should use make and female connector to plug them together.
I have attached some picture to show how I have done it:

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

additionnally i can see that you are using old emg module design: there was a mistake and you have to add a small wire between two resitors:

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

howardshu, 2025-04-26:
Thank you @Aightech for this response. The communication module I have seems different from the one in your photos since there is a gap in the top row where the single row female headers go. Is this still compatible?

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

Aightech, 2025-05-17:
Hi @howardshu , no it looks the same. The com module has 10pins and the emg module has 8 pins, when connecting them together, just ignore the 2 pins on each side of the com module. you should end up with both modules aligned!

Closed 2025-05-18.

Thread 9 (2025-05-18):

Pin headers on pos files

howardshu, 2025-05-18:
I'm looking to order new modules through JLPCB and was running into some issues uploading the CPL files for the [ADS1293](https://github.com/Aightech/CleverHand-hardware/blob/main/KiCad/modules/EMG_DAQ_ADS1293/production/EMG_DAQ_ADS1293_pos.csv)
and [communication module](https://github.com/Aightech/CleverHand-hardware/blob/main/KiCad/modules/COM_MOD/production/COM_MOD_pos.csv).
It turns out the issue was due to the positions being in inches instead of millimeters. Additionally, the header pins are not in the files and I would prefer to have them there so they could be assembled as well.
I was wondering about how you ordered your modules and whether you have any advice or extra files that could help. Thanks in advance for your help!

howardshu, 2025-05-20:
Update: I found the correctly formatted BOM/CPL in the jlpcb/production directory. Sorry for the confusion in the original post. However, I did notice that the [CPL for a single ADS1293](https://github.com/Aightech/CleverHand-hardware/blob/main/KiCad/modules/EMG_DAQ_ADS1293/jlcpcb/production_files/CPL-EMG_DAQ_ADS1293.csv) is empty. Could you update this when you get a chance?

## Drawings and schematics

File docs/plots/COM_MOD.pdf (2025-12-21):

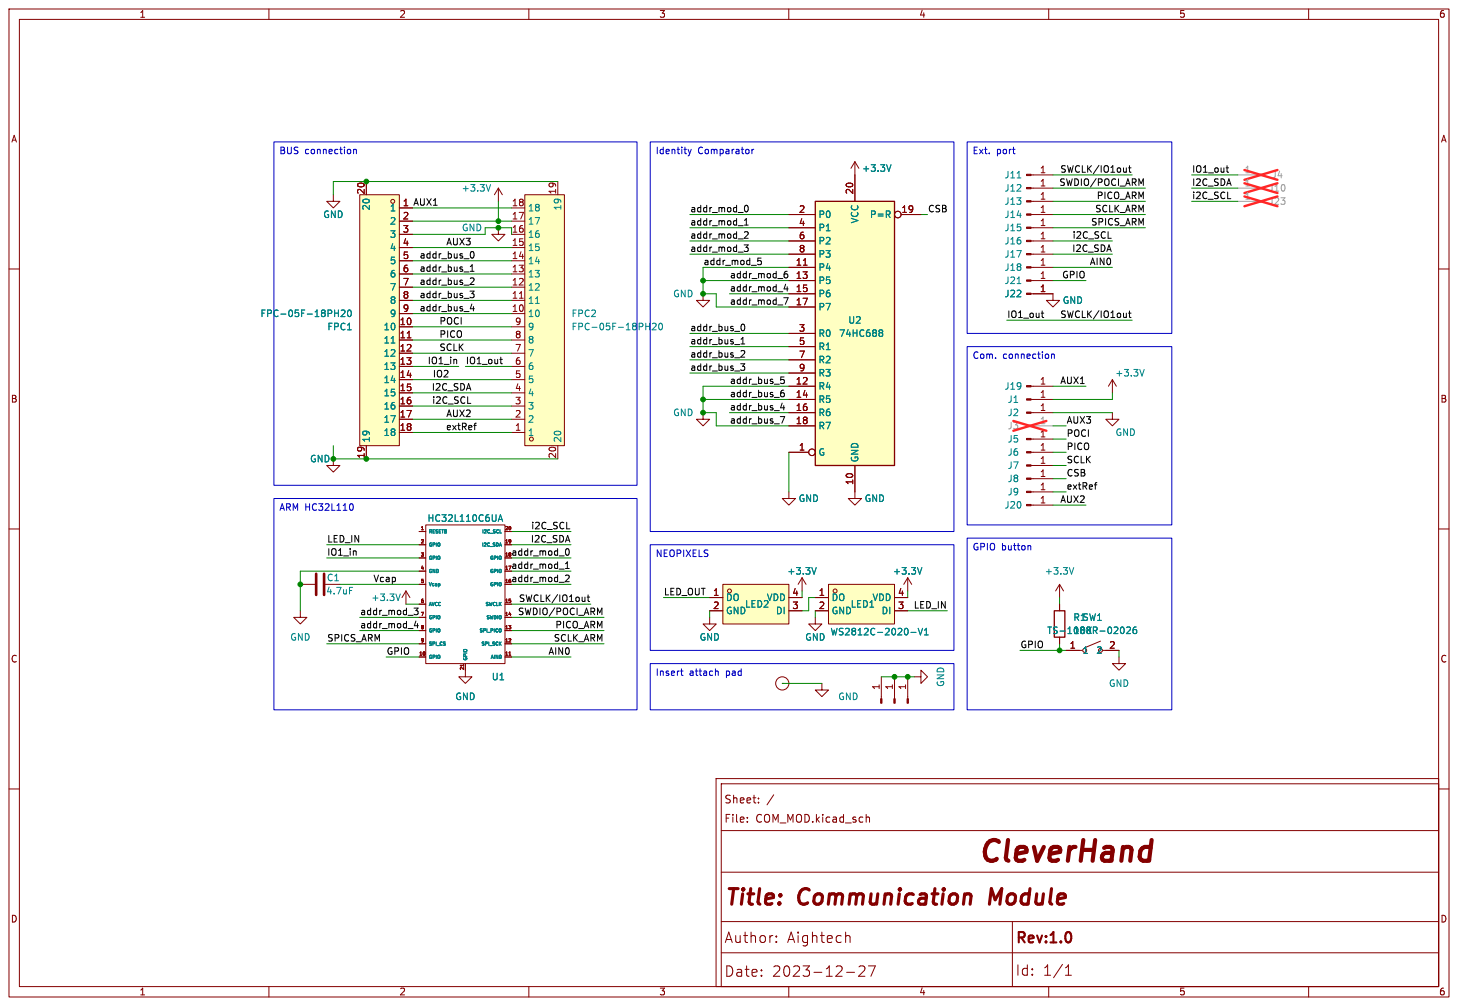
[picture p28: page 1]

Ext. port GPIO button

Insert attach pad NEOPIXELS

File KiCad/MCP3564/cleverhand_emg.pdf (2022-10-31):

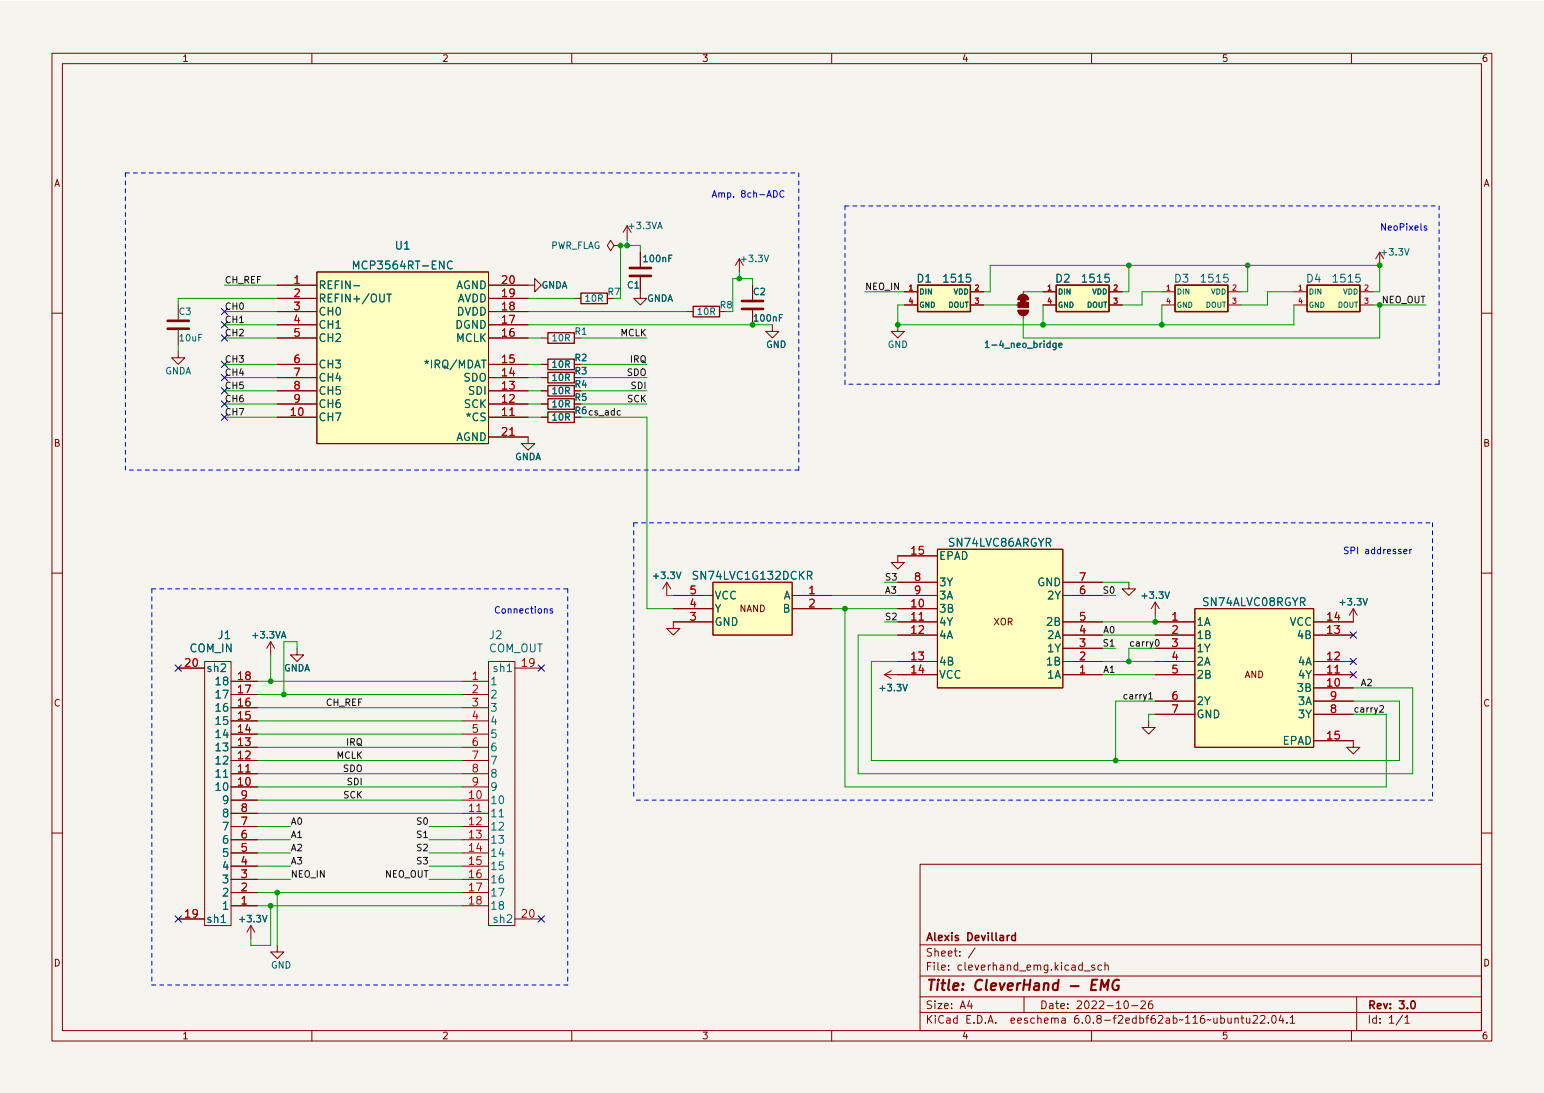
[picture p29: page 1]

File: cleverhand_emg.kicad_sch Sheet: / Alexis Devillard

Id: 1/1 Title: CleverHand - EMG

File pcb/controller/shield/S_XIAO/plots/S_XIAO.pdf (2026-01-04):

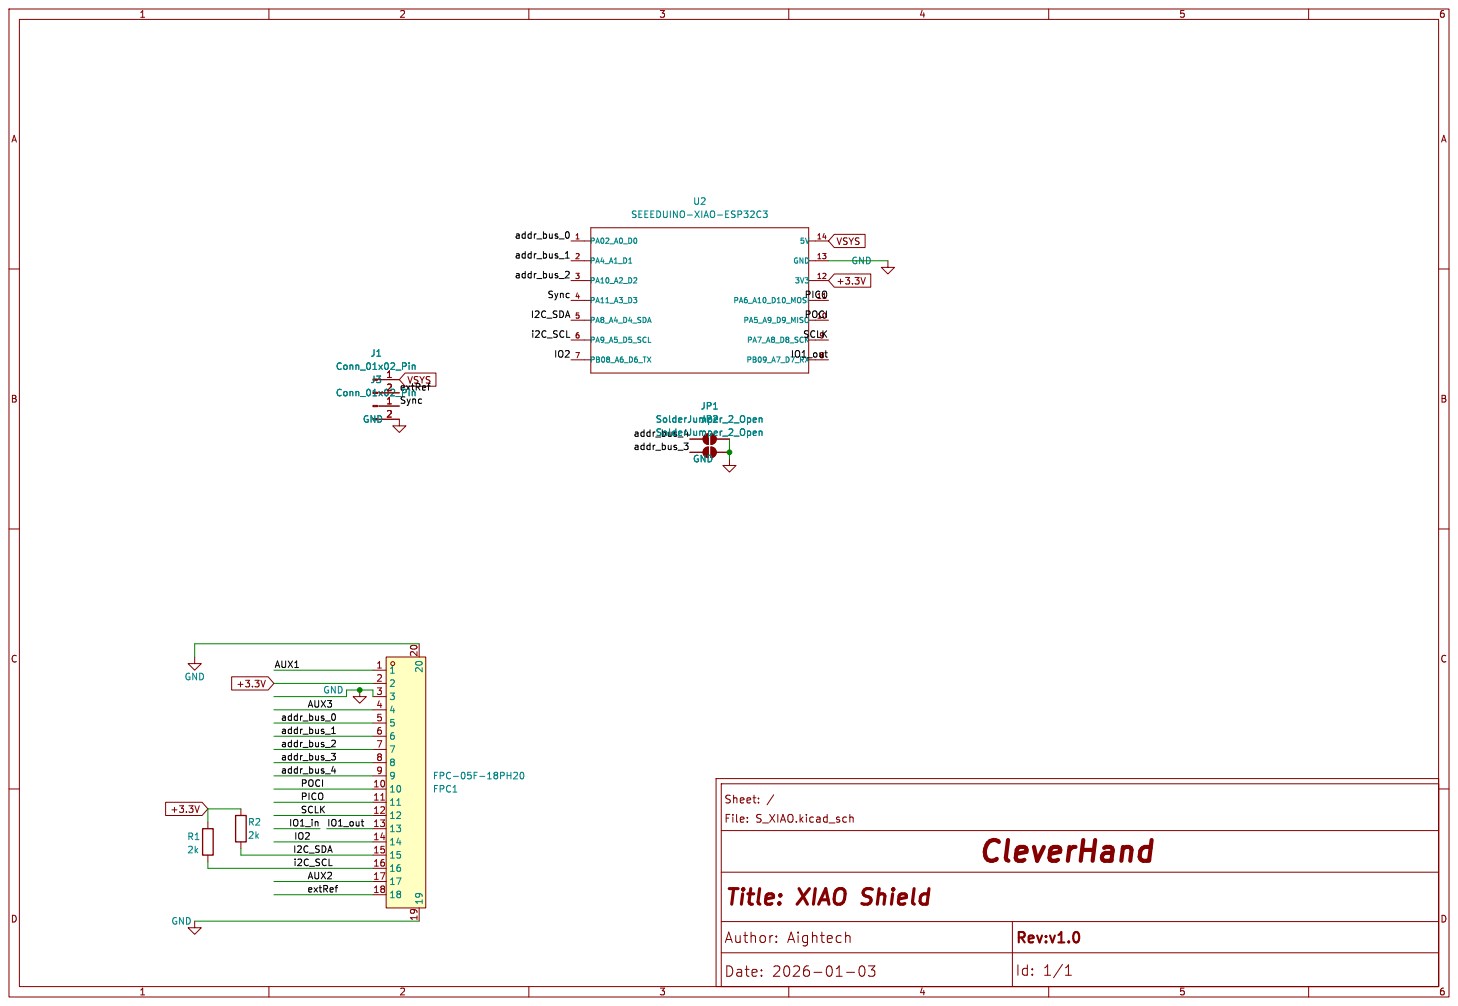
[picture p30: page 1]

extRef Sync POCI PICO

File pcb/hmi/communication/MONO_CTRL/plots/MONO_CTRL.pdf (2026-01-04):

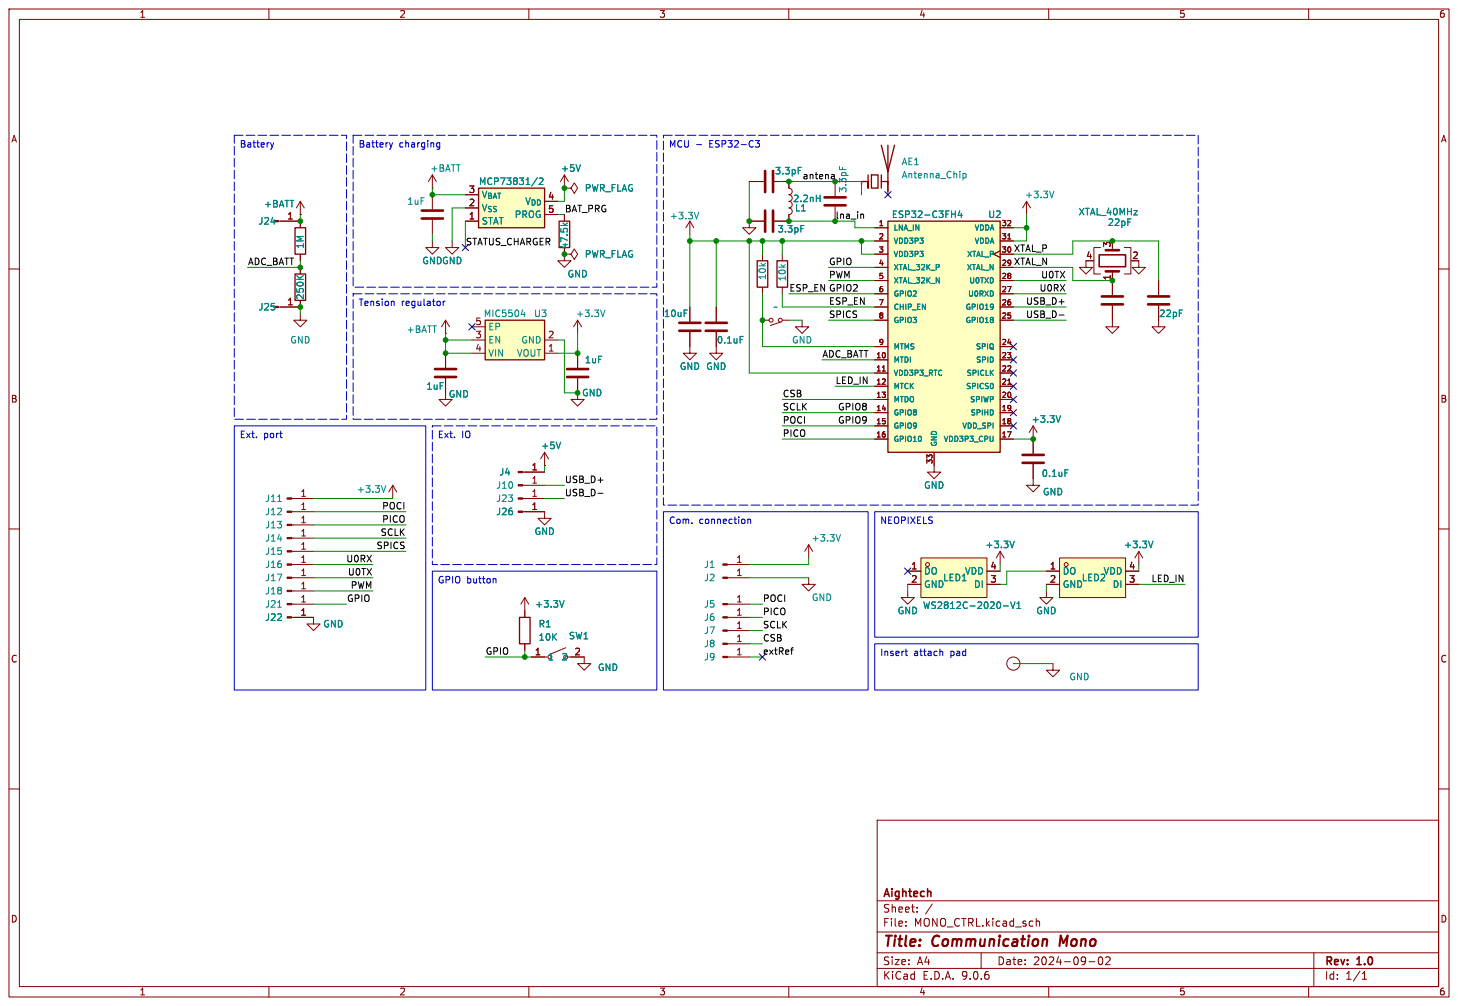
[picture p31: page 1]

3 XTAL_40MHz VDD3P3 2 VDD3P3 3 XTAL_32K_P 4 XTAL_32K_N 5 GPIO2 6 CHIP_EN 7 GPIO3 8 MTMS 9 MTDI 10 VDD3P3_RTC 11 MTCK 12 MTDO 13 GPIO8 14 GPIO9 15 GPIO10 16 GND 33 VDDA 32 VDDA 31 XTAL_P 30 XTAL_N 29 U0TXD 28 U0RXD 27 GPIO19 26 GPIO18 25 SPIQ 24 SPID 23 SPICLK 22 SPICS0 21 SPIWP 20 SPIHD 19 VDD_SPI 18 VDD3P3_CPU 17

CSB GPIO button Ext. IO

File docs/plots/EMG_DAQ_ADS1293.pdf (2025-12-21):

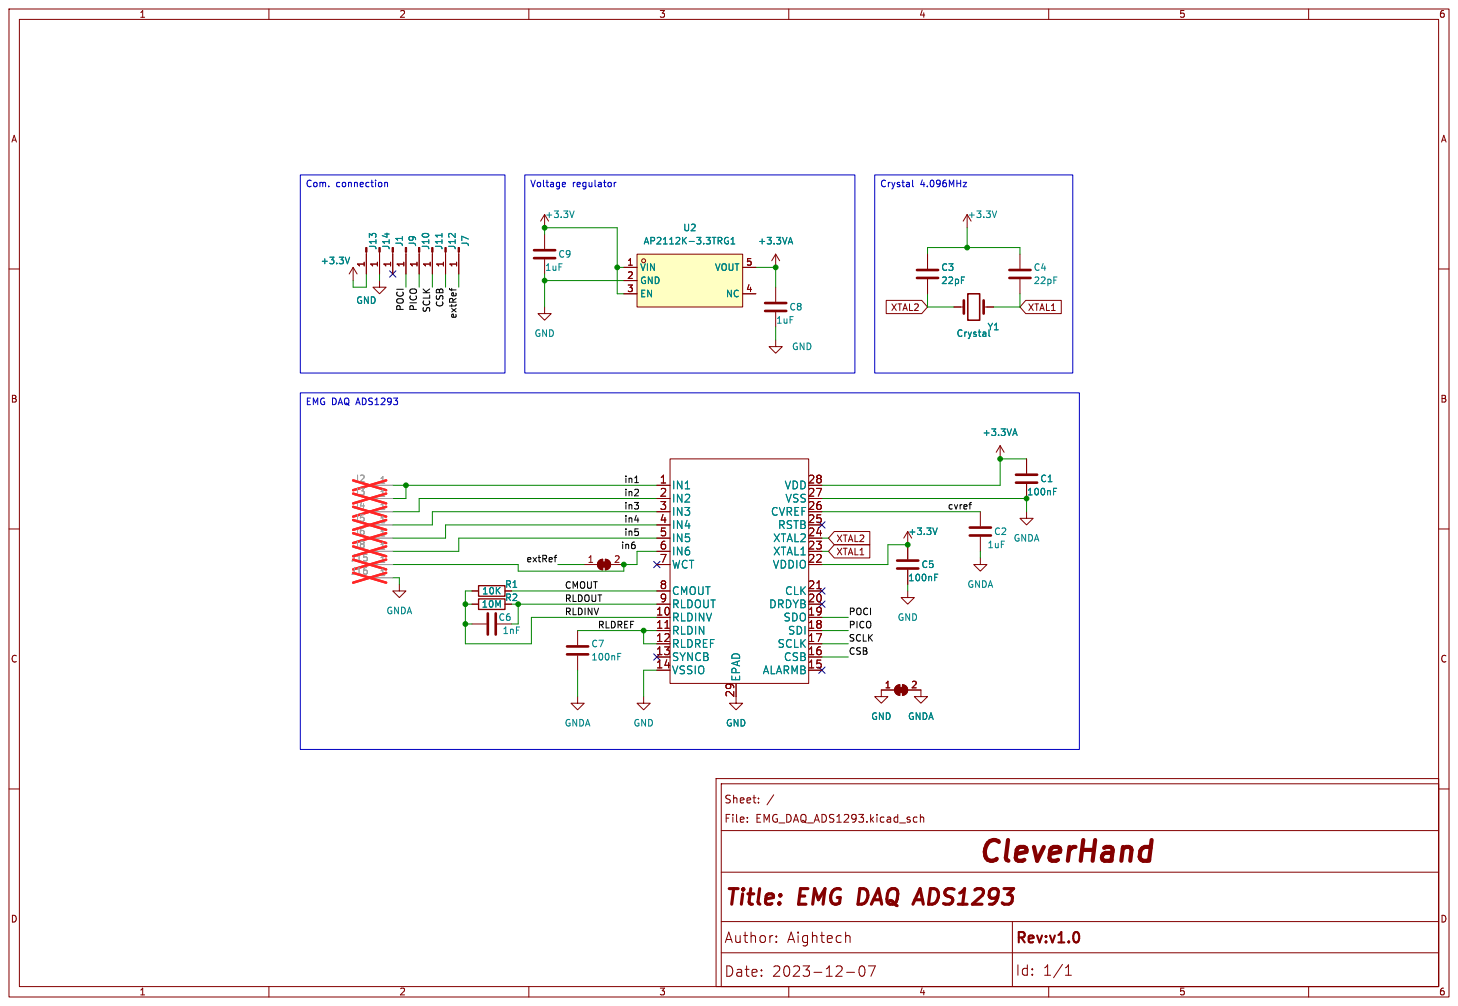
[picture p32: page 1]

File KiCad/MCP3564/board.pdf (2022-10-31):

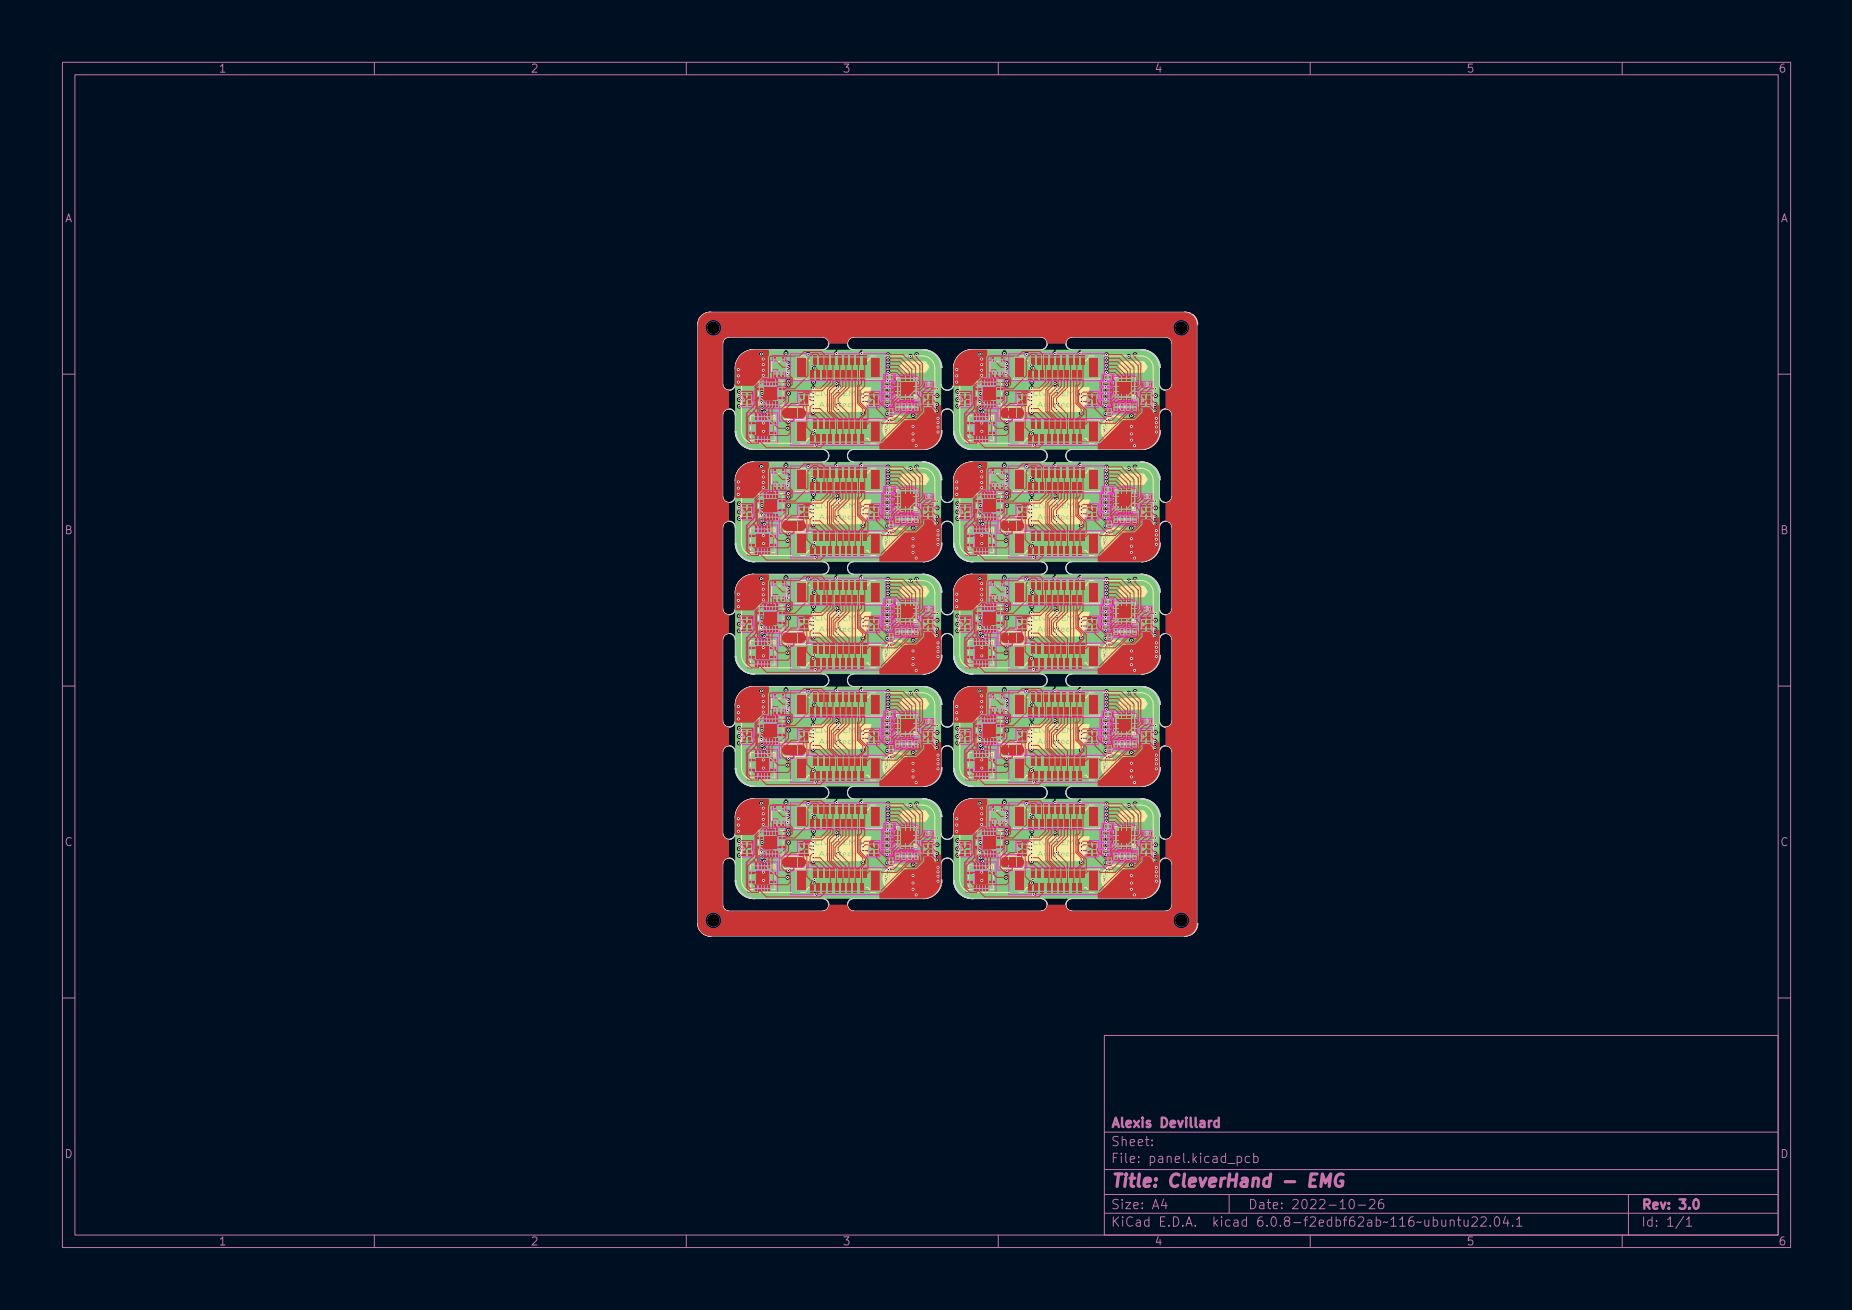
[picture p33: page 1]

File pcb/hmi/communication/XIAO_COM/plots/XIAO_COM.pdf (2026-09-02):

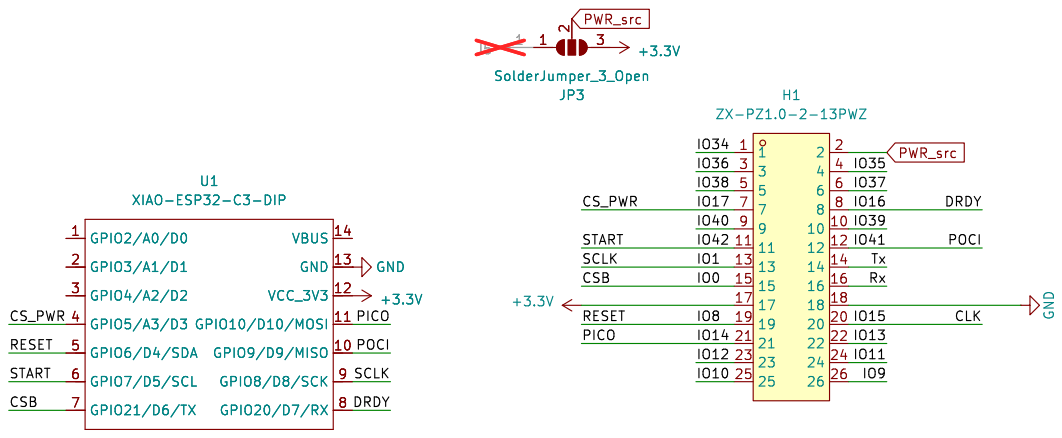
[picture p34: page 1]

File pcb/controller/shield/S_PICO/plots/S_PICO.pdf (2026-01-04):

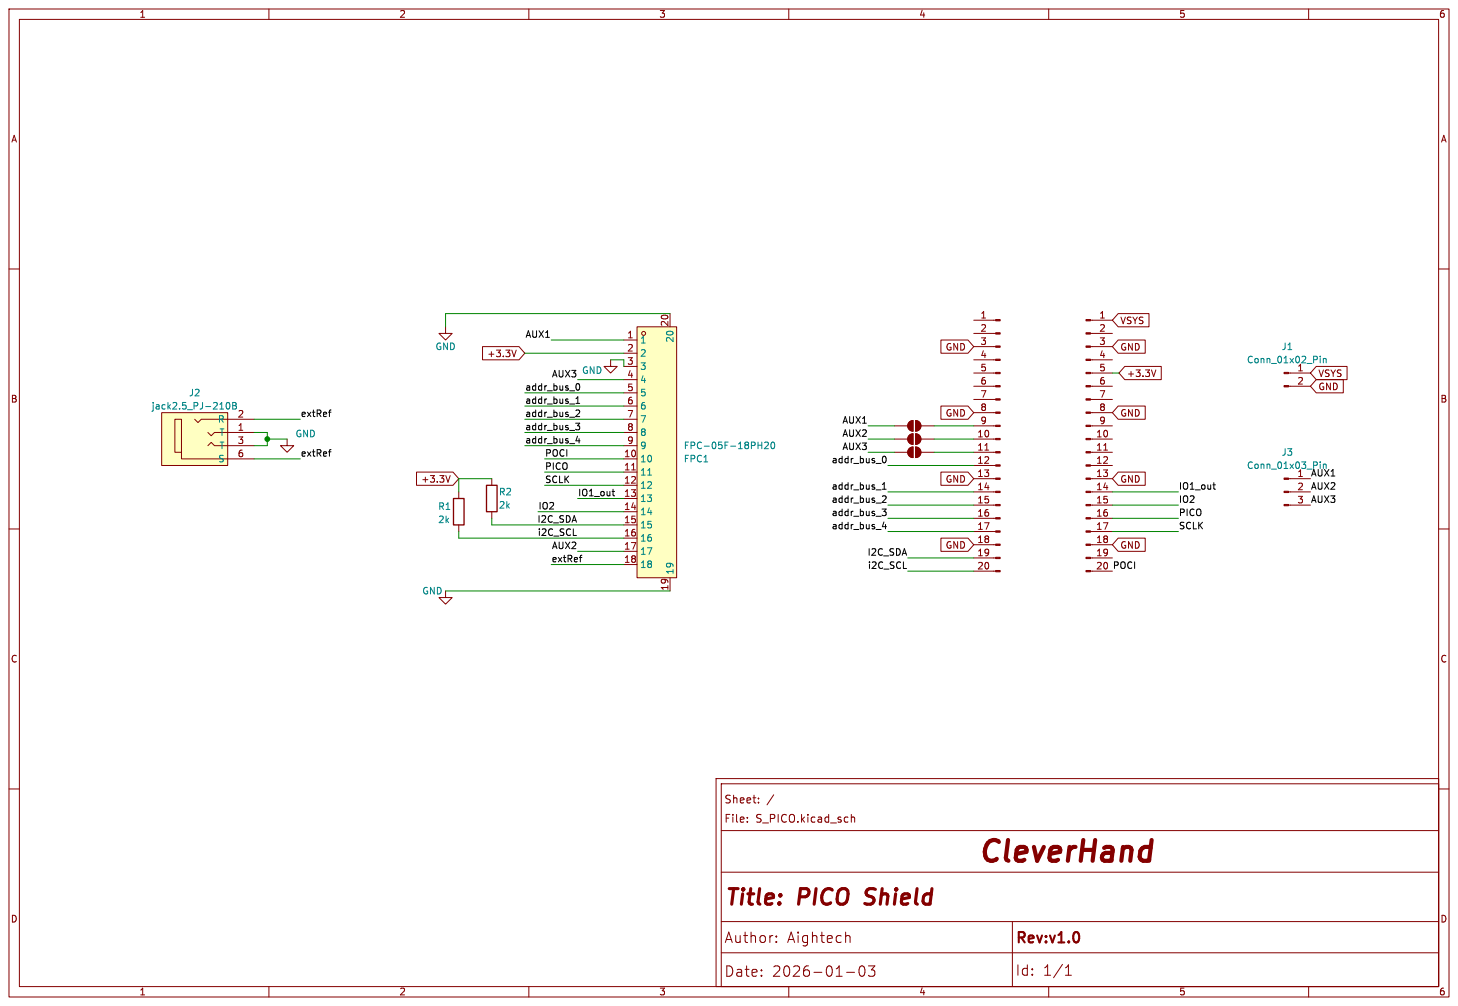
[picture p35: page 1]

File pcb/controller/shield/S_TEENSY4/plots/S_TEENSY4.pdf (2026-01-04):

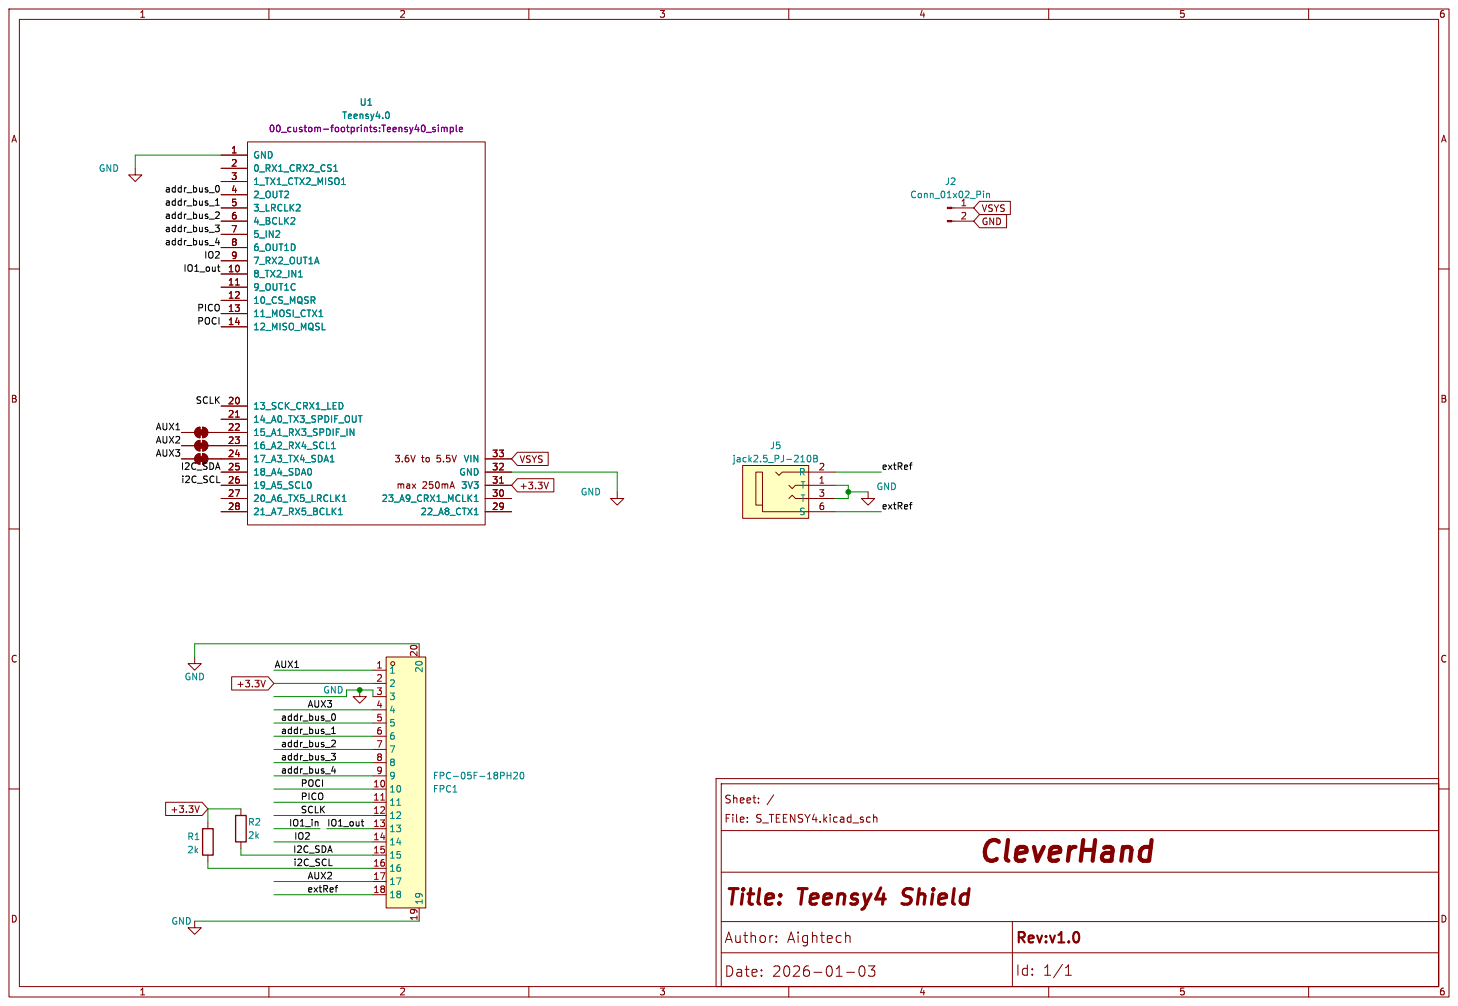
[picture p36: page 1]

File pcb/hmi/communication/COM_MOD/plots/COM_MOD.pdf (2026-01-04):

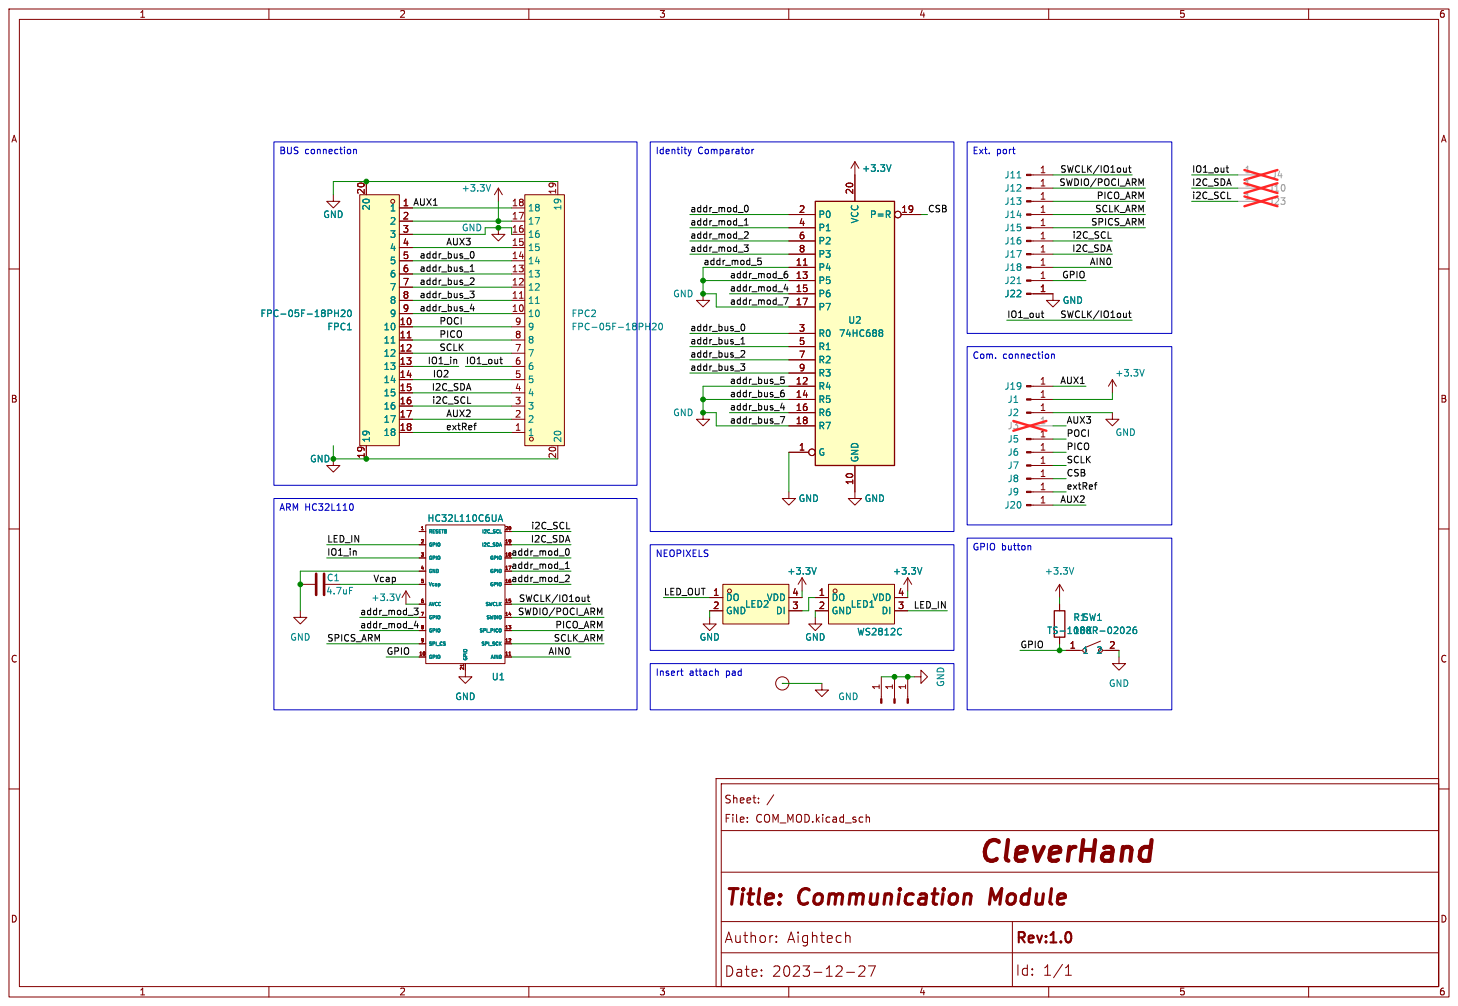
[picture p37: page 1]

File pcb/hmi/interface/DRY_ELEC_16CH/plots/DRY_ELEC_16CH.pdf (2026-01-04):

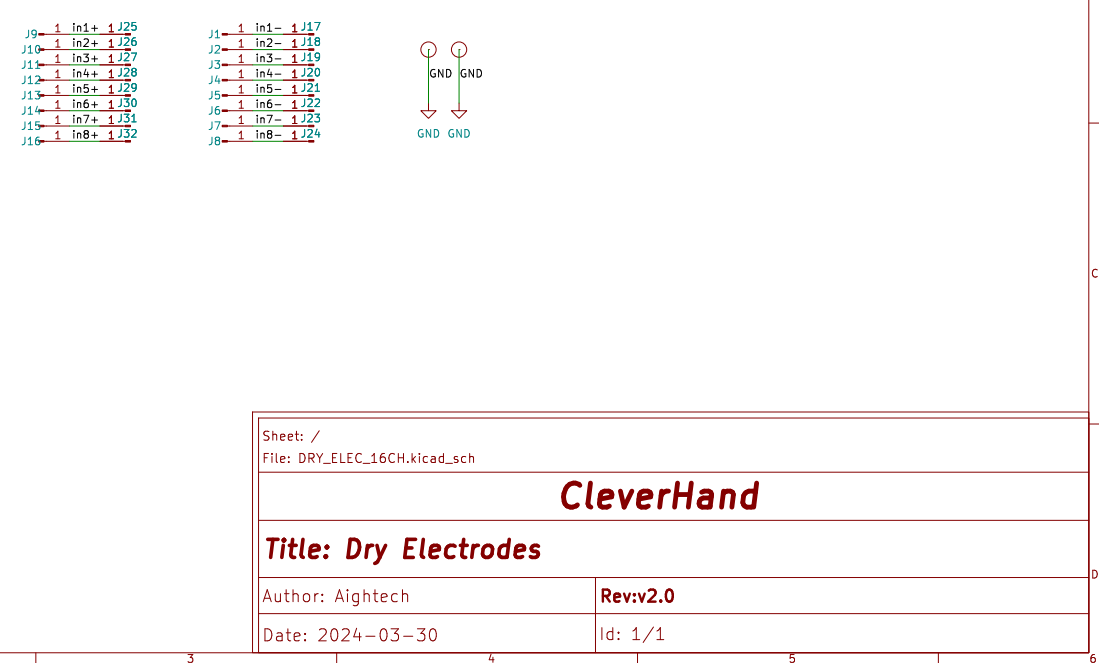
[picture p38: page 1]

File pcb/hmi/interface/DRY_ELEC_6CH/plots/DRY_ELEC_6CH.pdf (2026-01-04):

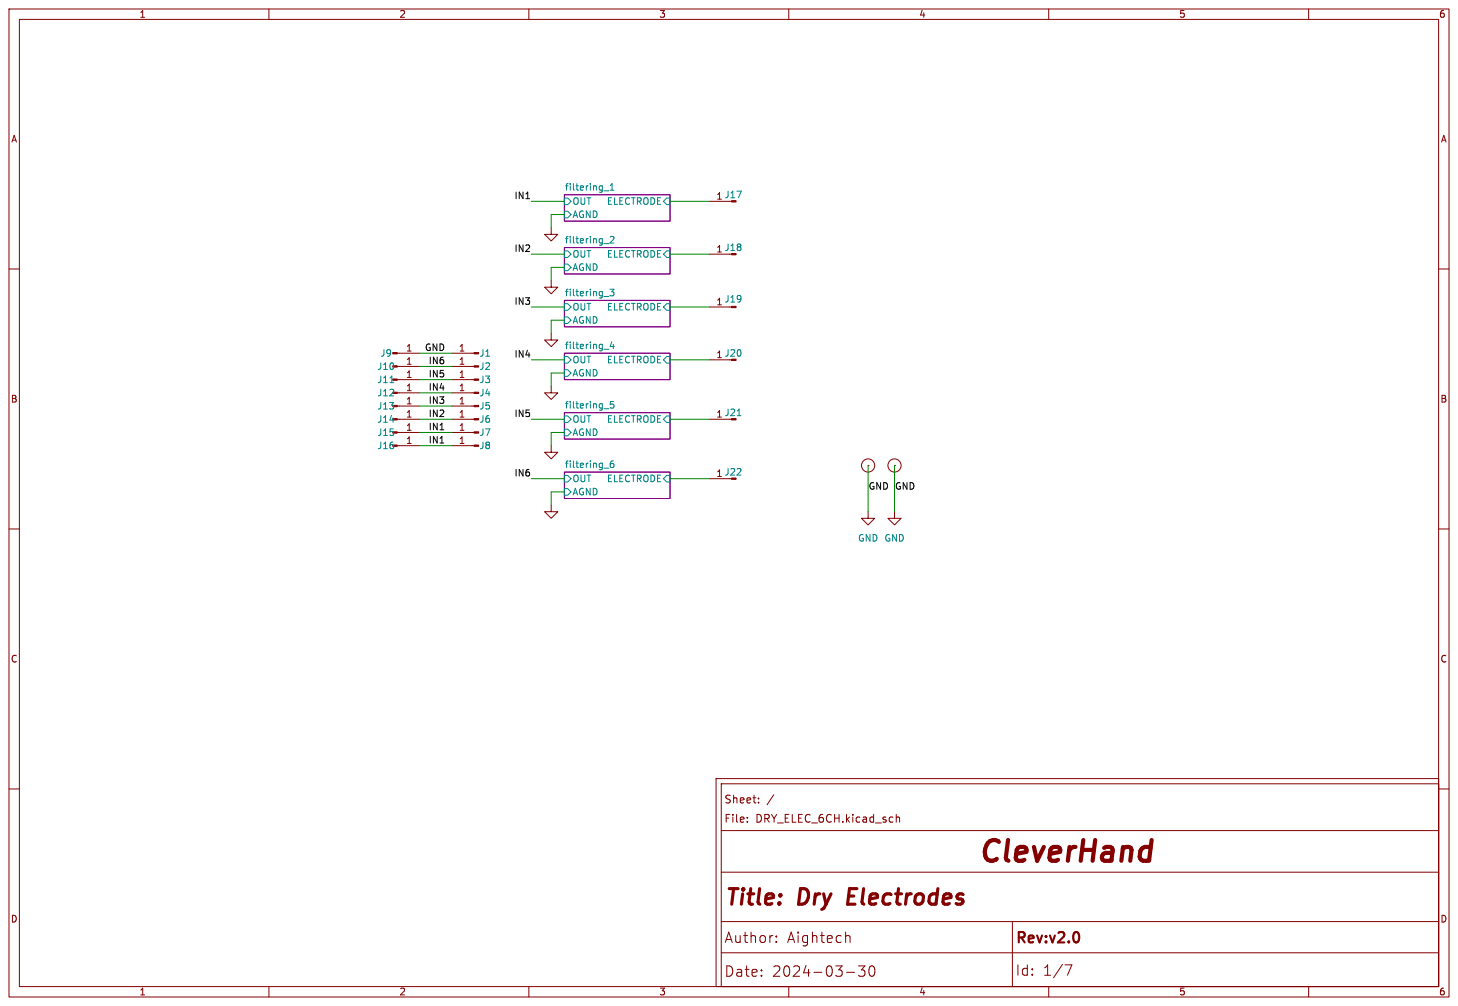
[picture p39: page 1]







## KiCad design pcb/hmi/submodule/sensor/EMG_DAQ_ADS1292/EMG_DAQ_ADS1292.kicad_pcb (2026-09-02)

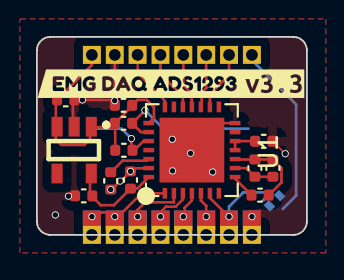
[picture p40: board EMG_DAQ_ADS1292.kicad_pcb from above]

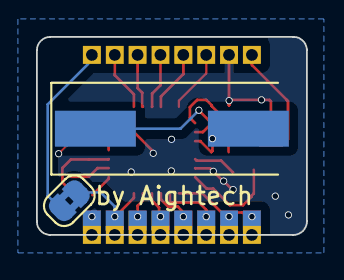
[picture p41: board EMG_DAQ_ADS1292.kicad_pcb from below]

Board: 4 copper layers, 15.0 x 11.0 mm, 33 parts (2 on the bottom side), 22 nets.

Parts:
C1, C5, C7: 100nF; C_0402_1005Metric
C2, C8, C9: 1uF; C_0402_1005Metric
C3, C4: 22pF; C_0402_1005Metric
C6: 1nF; C_0402_1005Metric
J1, J2, J3, J4, J5, J6, J7, J8, J9, J10, J11, J12, J13, J14, J15, J16: Conn_01x01_Pin; PinHeader_1x01_P1.27mm_Vertical
JP2: SolderJumper_2_Bridged; SolderJumper-2_P1.3mm_Bridged2Bar_RoundedPad1.0x1.5mm
R1: 10K; C_0402_1005Metric
R2: 10M; C_0402_1005Metric
U1: ADS1293CISQE-NOPB; ADS1293CISQE
U2: AP2112K-3.3TRG1; SOT-25-5_L2.9-W1.6-P0.95-LS2.8-BL
Y1: Crystal; Crystal_SMD_HC49-SD
kibuzzard-658D7E24: G***; kibuzzard-658D7E24
kibuzzard-69472C09: G***; kibuzzard-69472C09

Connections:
+3.3V: C3.1, C4.1, C5.1, C9.1, J13.1, U1.22 (VDDIO), U2.1 (VIN), U2.3 (EN)
+3.3VA: C1.1, C8.1, U1.28 (VDD), U2.5 (VOUT)
/CLK: J1.1, U1.21 (CLK)
/CMOUT: R1.2, U1.8 (CMOUT)
/CSB: J12.1, U1.16 (CSB)
/PICO: J10.1, U1.18 (SDI)
/POCI: J9.1, U1.19 (SDO)
/RLDINV: C6.1, R1.1, R2.1, U1.10 (RLDINV)
/RLDOUT: C6.2, R2.2, U1.9 (RLDOUT)
/RLDREF: C7.1, U1.11 (RLDIN), U1.12 (RLDREF)
/SCLK: J11.1, U1.17 (SCLK)
/cvref: C2.1, U1.26 (CVREF)
/extRef: J7.1, JP2.1 (A)
/in1: J2.1, J3.1, U1.1 (IN1)
/in2: J4.1, U1.2 (IN2)
/in3: J5.1, U1.3 (IN3)
/in4: J6.1, U1.4 (IN4)
/in5: J8.1, U1.5 (IN5)
/in6: J15.1, JP2.2 (B), U1.6 (IN6)
GND: C1.2, C2.2, C5.2, C7.2, C8.2, C9.2, J14.1, J16.1, U1.14 (VSSIO), U1.27 (VSS), U1.29 (EPAD), U2.2 (GND)
XTAL1: C4.2, U1.23 (XTAL1), Y1.1
XTAL2: C3.2, U1.24 (XTAL2), Y1.2

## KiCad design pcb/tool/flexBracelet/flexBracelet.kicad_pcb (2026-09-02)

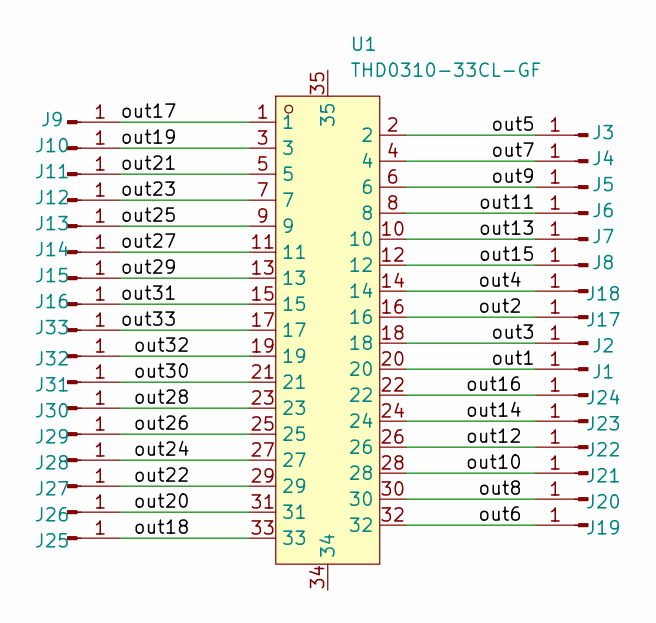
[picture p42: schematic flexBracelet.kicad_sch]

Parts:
J1, J2, J3, J4, J5, J6, J7, J8, J9, J10, J11, J12, J13, J14, J15, J16, J17, J18, J19, J20, J21, J22, J23, J24, J25, J26, J27, J28, J29, J30, J31, J32, J33: Conn_01x01_Pin; dryElec8x4mm
U1: THD0310-33CL-GF; FPC 33POS 0.3MM; LCSC Part C19078615

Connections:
/out1: J1.1 (Pin_1_1), U1.20 (20_20)
/out2: J17.1 (Pin_1_1), U1.16 (16_16)
/out3: J2.1 (Pin_1_1), U1.18 (18_18)
/out4: J18.1 (Pin_1_1), U1.14 (14_14)
/out5: J3.1 (Pin_1_1), U1.2 (2_2)
/out6: J19.1 (Pin_1_1), U1.32 (32_32)
/out7: J4.1 (Pin_1_1), U1.4 (4_4)
/out8: J20.1 (Pin_1_1), U1.30 (30_30)
/out9: J5.1 (Pin_1_1), U1.6 (6_6)
/out10: J21.1 (Pin_1_1), U1.28 (28_28)
/out11: J6.1 (Pin_1_1), U1.8 (8_8)
/out12: J22.1 (Pin_1_1), U1.26 (26_26)
/out13: J7.1 (Pin_1_1), U1.10 (10_10)
/out14: J23.1 (Pin_1_1), U1.24 (24_24)
/out15: J8.1 (Pin_1_1), U1.12 (12_12)
/out16: J24.1 (Pin_1_1), U1.22 (22_22)
/out17: J9.1 (Pin_1_1), U1.1 (1_1)
/out18: J25.1 (Pin_1_1), U1.33, U1.34 (33_33)
/out19: J10.1 (Pin_1_1), U1.3 (3_3)
/out20: J26.1 (Pin_1_1), U1.31 (31_31)
/out21: J11.1 (Pin_1_1), U1.5 (5_5)
/out22: J27.1 (Pin_1_1), U1.29 (29_29)
/out23: J12.1 (Pin_1_1), U1.7 (7_7)
/out24: J28.1 (Pin_1_1), U1.27 (27_27)
/out25: J13.1 (Pin_1_1), U1.9 (9_9)
/out26: J29.1 (Pin_1_1), U1.25 (25_25)
/out27: J14.1 (Pin_1_1), U1.11 (11_11)
/out28: J30.1 (Pin_1_1), U1.23 (23_23)
/out29: J15.1 (Pin_1_1), U1.13 (13_13)
/out30: J31.1 (Pin_1_1), U1.21 (21_21)
/out31: J16.1 (Pin_1_1), U1.15 (15_15)
/out32: J32.1 (Pin_1_1), U1.19 (19_19)
/out33: J33.1 (Pin_1_1), U1.17 (17_17)

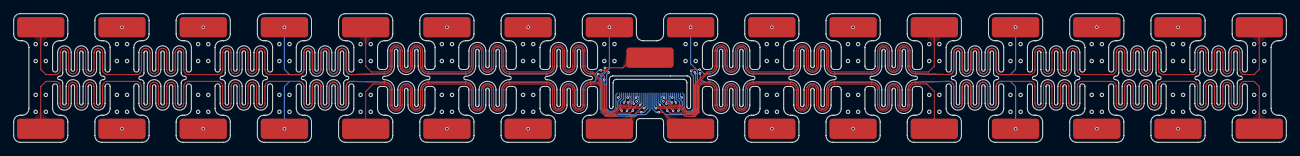
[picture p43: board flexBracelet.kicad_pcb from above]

Board: 4 copper layers, 188.0 x 19.0 mm, 34 parts (1 on the bottom side), 33 nets.

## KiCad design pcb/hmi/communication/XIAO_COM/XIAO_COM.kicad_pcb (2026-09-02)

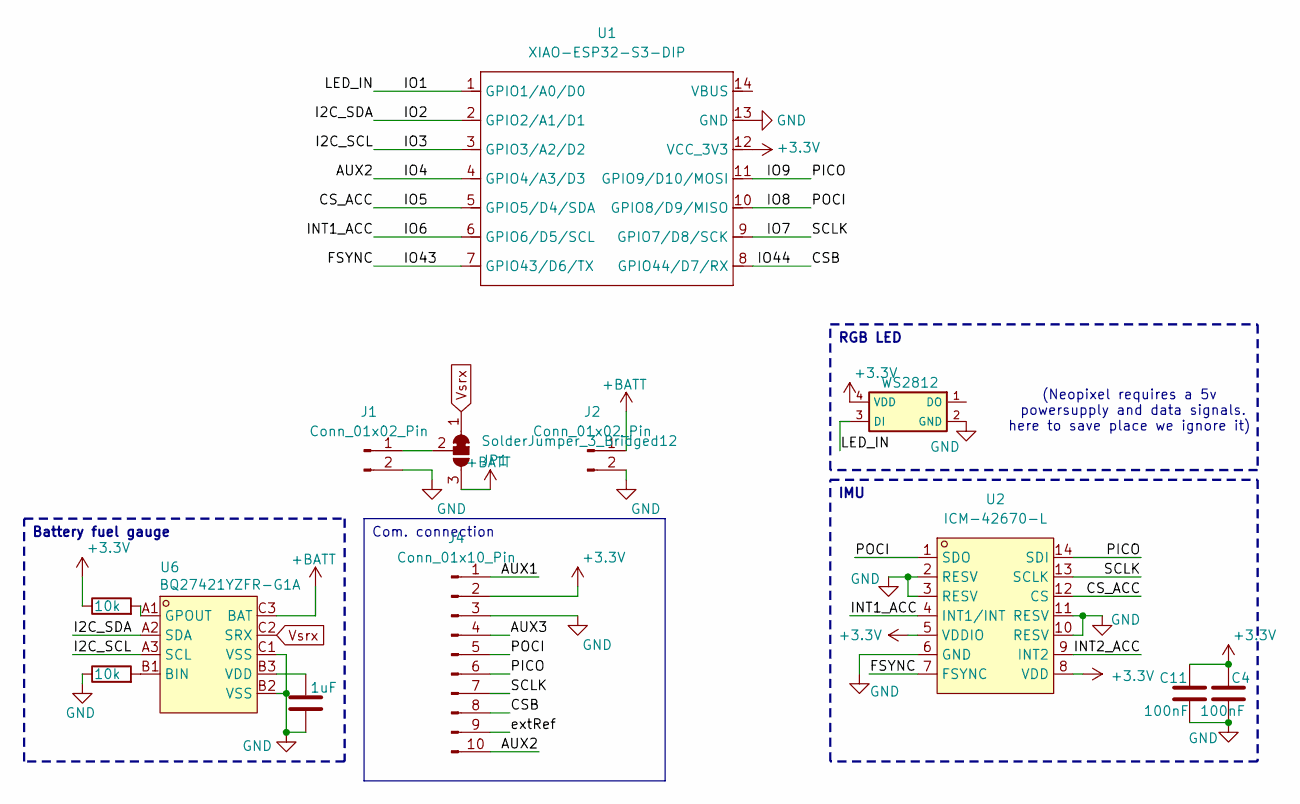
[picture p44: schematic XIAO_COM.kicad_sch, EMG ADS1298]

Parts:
C4, C11: 100nF; C_0402_1005Metric; LCSC C1525
C28: 1uF; C_0201_0603Metric; LCSC C52923
J1, J2: Conn_01x02_Pin; PinHeader_1x02_P1.27mm_Vertical
J4: Conn_01x10_Pin; PinHeader_1x10_P1.27mm_Vertical
JP1: SolderJumper_3_Bridged12; SolderJumper-3_P1.3mm_Bridged12_RoundedPad1.0x1.5mm_NumberL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
R10, R17: 10k; R_0201_0603Metric; LCSC C25744
U1: XIAO-ESP32-S3-DIP; XIAO-ESP32S3-DIP
U2: ICM-42670-L; LGA-14_L3.0-W2.5-P0.50-TL_QMI8658A; LCSC Part C49073546
U6: BQ27421YZFR-G1A; DSBGA-9_L1.5-W1.5-R3-C3-P0.50-BL; LCSC Part C139621
U10: WS2812; LED-SMD_4P-L2.0-W2.0-TL_WS2812B-2020; LCSC C2976072

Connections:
+3.3V: C4.1, C11.1, J4.2, R17.1, U1.12 (VCC_3V3), U2.5 (VDDIO), U2.8 (VDD), U10.4 (VDD)
+BATT: J2.1, JP1.3 (B), U6.C3 (BAT)
/AUX1: J4.1
/AUX2: J4.10, U1.4 (GPIO4/A3/D3)
/AUX3: J4.4
/CSB: J4.8, U1.8 (GPIO44/D7/RX)
/CS_ACC: U1.5 (GPIO5/D4/SDA), U2.12 (CS)
/FSYNC: U1.7 (GPIO43/D6/TX), U2.7 (FSYNC)
/I2C_SCL: U1.3 (GPIO3/A2/D2), U6.A3 (SCL)
/I2C_SDA: U1.2 (GPIO2/A1/D1), U6.A2 (SDA)
/INT1_ACC: U1.6 (GPIO6/D5/SCL), U2.4 (INT1/INT)
/INT2_ACC: U2.9 (INT2)
/IO1: U1.1 (GPIO1/A0/D0), U10.3 (DI)
/IO7: J4.7, U1.9 (GPIO7/D8/SCK), U2.13 (SCLK)
/IO8: J4.5, U1.10 (GPIO8/D9/MISO), U2.1 (SDO)
/IO9: J4.6, U1.11 (GPIO9/D10/MOSI), U2.14 (SDI)
/extRef: J4.9
GND: C4.2, C11.2, C28.2, J1.2, J2.2, J4.3, R10.1, U1.13 (GND), U2.2 (RESV), U2.3 (RESV), U2.6 (GND), U2.10 (RESV), U2.11 (RESV), U6.B2 (VSS), U6.C1 (VSS), U10.2 (GND)
unnamed: J1.1, JP1.2 (C)
unnamed: R10.2, U6.B1 (BIN)
unnamed: R17.2, U6.A1 (GPOUT)
unnamed: C28.1, U6.B3 (VDD)
Vsrx: JP1.1 (A), U6.C2 (SRX)

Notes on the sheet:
(Neopixel requires a 5v powersupply and data signals. here to save place we ignore it)
RGB LED
IMU
Battery fuel gauge
Com. connection

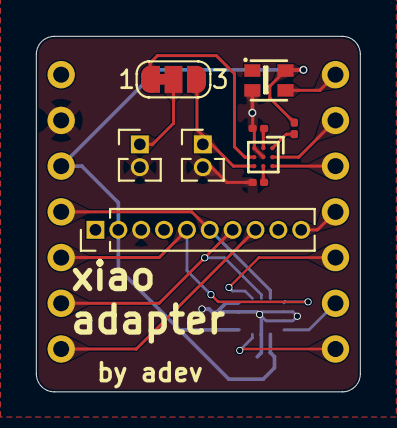
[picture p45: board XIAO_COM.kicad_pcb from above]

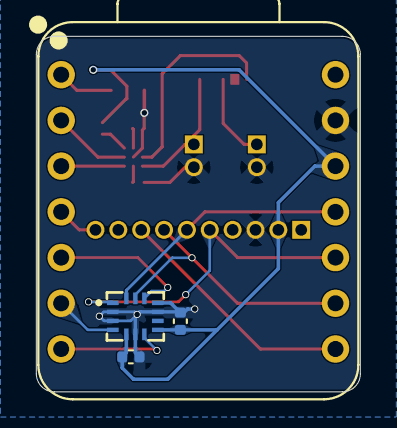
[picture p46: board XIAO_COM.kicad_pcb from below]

Board: 2 copper layers, 18.0 x 19.8 mm, 13 parts (4 on the bottom side), 19 nets.

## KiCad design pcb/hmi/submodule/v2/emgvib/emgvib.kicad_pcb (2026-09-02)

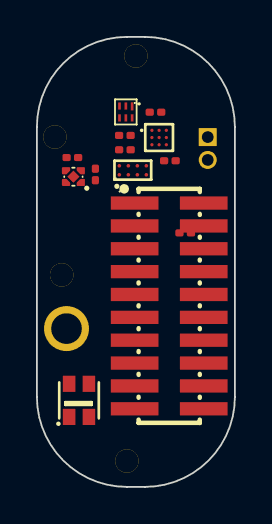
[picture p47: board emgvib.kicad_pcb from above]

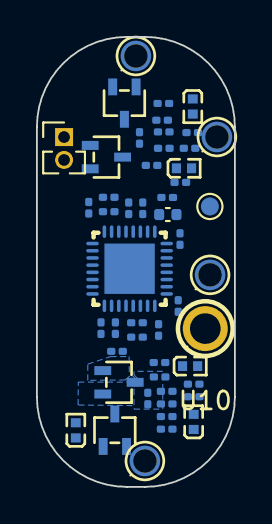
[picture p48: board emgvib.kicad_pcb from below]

Board: 4 copper layers, 11.0 x 25.0 mm, 63 parts (50 on the bottom side), 35 nets, no tracks yet.

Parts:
C57, C58, C60, C61, C62, C119, C120, C123, C124, C126, C130, C131: 4.7nF; C_0201_0603Metric
C59: 1.5nF; C_0201_0603Metric
C66, C69, C71, C72, C133, C135: 1uF; C_0201_0603Metric
C127: 10uF; C_0402_1005Metric
C128, C129: 100nF; C_0201_0603Metric
D18, D19, D20, D41, D42: PGB1010402KR; D0402
D21, D22, D45, D46: BAT54SWFILM; SOT-323-3_L2.0-W1.3-P1.30-LS2.1-BR
J7: Conn_01x02_Pin; PinHeader_1x02_P1.27mm_Vertical
R48, R49, R52, R53, R63, R64, R97, R98, R101, R102, R103, R104, R105, R106: 10K; R_0201_0603Metric
R50, R54: 100k; R_0201_0603Metric
R51: 1M; R_0201_0603Metric
R55: 0R; R_0201_0603Metric
TP_VDD_6: TestPoint; TestPoint_Pad_D1.0mm
U1: PZ127-2-10-S; HDR-SMD_PZ127-2-10-S
U2: PCA9306YZTR; DSBGA-8_L1.9-W0.9-R2-C4-P0.50-BL
U3: SN74LVC1G04DSFR; UDFN-6_L1.0-W1.0-P0.35-BL
U5, U6, U8, U9: YZP0120-16020-01; SMD_YZP0120-16020-01
U7: WS2812-2020; LED-SMD_4P-L2.0-W2.0-TL_WS2812B-2020
U10: YZP0664-20036-01; CONN-TH_YZP0664-20036-01
U12: ADS1292RIRSMR; QFN-32_L4.0-W4.0-P0.40-TL-EP2.8
U23: TPS7A0230PDQNR; UDFN-4_L1.0-W1.0-P0.65-TL
U27: DRV2625YFFR; DSBGA-9_L1.4-W1.3-R3-C3-P0.40-BL

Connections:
/CS: R106.1, U3.2 (A), U12.18 (~CS)
/ELEC_N1: D19.2, R49.2, U5.1 (1_1)
/ELEC_N2: D42.2, R98.2, U8.1 (1_1)
/ELEC_P1: D18.2, R48.2, U10.1 (1_1)
/ELEC_P2: D41.2, R97.2, U6.1 (1_1)
/IN_N1: C61.1, C62.2, D22.3, R53.1, U12.3 (IN1N)
/IN_N2: C124.1, C126.2, D46.3, R102.1, U12.5 (IN2N)
/IN_P1: C60.1, C62.1, D21.3, R52.1, U12.4 (IN1P)
/IN_P2: C123.1, C126.1, D45.3, R101.1, U12.6 (IN2P)
/OUTN: J7.2, U27.C3 (OUT-)
/OUTP: J7.1, U27.A3 (OUT+)
/RLD_IN: R54.2, R55.1, U12.29 (RLDIN/RLDREF)
/RLD_INV: C59.2, R51.1, U12.28 (RLDINV)
/RLD_OUT: C59.1, R50.1, R51.2, R54.1, U12.30 (RLDOUT)
/SCL: R63.1, U2.C2 (SCL2), U27.C1 (SCL)
/SDA: R64.1, U2.D2 (SDA2), U27.B1 (SDA)
/VDDA: C69.2, C128.1, D21.2, D22.2, D45.2, D46.2, TP_VDD_6.1 (1_1), U12.12 (AVDD), U23.1 (OUT)
/VREFP: C127.1, C129.1, U12.9 (VREFP)
GND: C57.2, C58.2, C60.2, C61.2, C66.1, C69.1, C71.1, C72.1, C119.2, C120.2, C123.2, C124.2, C127.2, C128.2, C129.2, C133.1, C135.2, D18.1, D19.1, D20.2, D21.1, D22.1, D41.1, D42.1, D45.1, D46.1, R55.2, R103.1, U2.A1 (GND), U3.3 (GND), U7.2 (GND), U12.10 (VREFN), U12.13 (AVSS), U12.24 (DGND), U12.33 (EP), U23.2 (GND), U23.5 (EP), U27.A1 (TRIG/INTZ), U27.B3 (GND)
unnamed: C57.1, R48.1, R52.2
unnamed: C58.1, R49.1, R53.2
unnamed: C119.1, R97.1, R101.2
unnamed: C120.1, R98.1, R102.2
unnamed: D20.1, R50.2, U9.1 (1_1)
unnamed: U2.A2 (EN), U3.4 (Y)
unnamed: R103.2, R104.2, U12.14 (CLKSEL)
unnamed: C131.1, U12.1 (PGA1N)
unnamed: C131.2, U12.2 (PGA1P)
unnamed: C130.1, U12.7 (PGA2N)
unnamed: C130.2, U12.8 (PGA2P)
unnamed: C133.2, U12.11 (VCAP1)
unnamed: C135.1, U12.27 (VCAP2)
unnamed: R105.2, U12.15 (~PWDN/~RESET)
unnamed: C71.2, U27.A2 (REG)
VDDF: C66.2, C72.2, R63.2, R64.2, R104.1, R105.1, R106.2, U2.B1 (VREF1), U2.B2 (VREF2), U3.6 (VCC), U7.4 (VDD), U12.23 (DVDD), U23.3 (EN), U23.4 (IN), U27.B2 (NRST), U27.C2 (VDD)

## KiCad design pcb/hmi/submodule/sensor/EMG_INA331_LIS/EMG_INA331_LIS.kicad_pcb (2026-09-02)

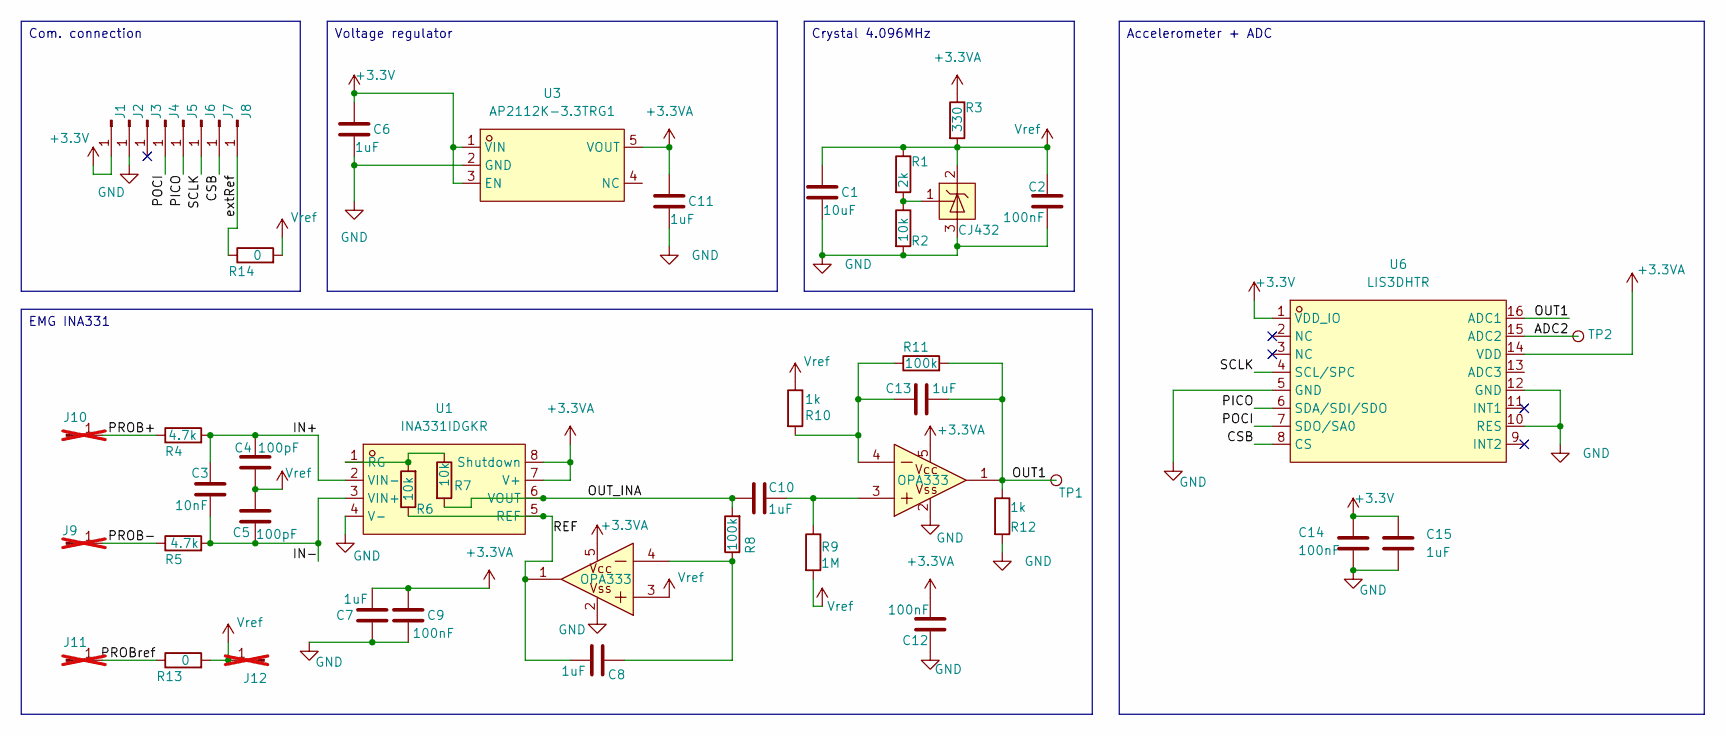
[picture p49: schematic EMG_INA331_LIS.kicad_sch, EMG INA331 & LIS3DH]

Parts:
C1: 10uF; C_0402_1005Metric
C2, C9, C12, C14: 100nF; C_0402_1005Metric
C3: 10nF; C_0402_1005Metric
C4, C5: 100pF; C_0402_1005Metric; LCSC C1546
C6, C7, C8, C10, C11, C13, C15: 1uF; C_0402_1005Metric
J1, J2, J3, J4, J5, J6, J7, J8: Conn_01x01_Pin; PinHeader_1x01_P1.27mm_Vertical
J9, J10, J11, J12: Conn_01x01_Pin; PinHeader_1x01_P1.27mm_Vertical; not fitted
R1: 2k; R_0402_1005Metric; LCSC C4109
R2: 10k; R_0402_1005Metric; LCSC C25744
R3: 330; R_0402_1005Metric; LCSC C25104
R4: 4.7k; R_0402_1005Metric; LCSC C25900
R5: 4.7k; R_0402_1005Metric
R6, R7: 10k; R_0402_1005Metric
R8: 100k; R_0402_1005Metric
R9: 1M; R_0402_1005Metric; LCSC C26083
R10: 1k; R_0402_1005Metric; LCSC C11702
R11: 100k; R_0402_1005Metric; LCSC C25741
R12: 1k; R_0402_1005Metric
R13, R14: 0; R_0402_1005Metric; LCSC C17168
TP1, TP2: TestPoint; TestPoint_Pad_D1.0mm
U1: INA331IDGKR; VSSOP-8_L3.0-W3.0-P0.65-LS5.0-BL; LCSC Part C2863664
U2, U4: OPA333; SOT-23-5_L2.9-W1.6-P0.95-LS2.8-BR; LCSC Part C3007938
U3: AP2112K-3.3TRG1; SOT-25-5_L2.9-W1.6-P0.95-LS2.8-BL; LCSC Part C51118
U5: CJ432; SOT-23-3_L2.9-W1.3-P1.90-LS2.4-BR; LCSC Part C2910208
U6: LIS3DHTR; LGA-16_L3.0-W3.0-P0.50-TL; LCSC Part C15134

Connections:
+3.3V: C6.1, C14.1, C15.1, J1.1 (Pin_1_1), U3.1 (VIN), U3.3 (EN), U6.1 (VDD_IO)
+3.3VA: C7.2, C9.1, C11.1, C12.1, R3.1, U1.7 (V+), U1.8 (Shutdown), U2.5 (V+), U3.5 (VOUT), U4.5 (V+), U6.14 (VDD)
/ADC2: TP2.1 (1_1), U6.15 (ADC2)
/CSB: J7.1 (Pin_1_1), U6.8 (CS)
/IN+: C3.1, C4.1, R4.2, U1.2 (VIN-)
/IN-: C3.2, C5.2, R5.2, U1.3 (VIN+)
/OUT1: C13.2, R11.2, R12.1, TP1.1 (1_1), U4.1 (OUT), U6.16 (ADC1)
/OUT_INA: C10.1, R7.2, R8.2, U1.6 (VOUT)
/PICO: J5.1 (Pin_1_1), U6.6 (SDA/SDI/SDO)
/POCI: J4.1 (Pin_1_1), U6.7 (SDO/SA0)
/PROB+: J10.1 (Pin_1_1), R4.1
/PROB-: J9.1 (Pin_1_1), R5.1
/PROBref: J11.1 (Pin_1_1), R13.1
/REF: C8.1, R6.1, U1.5 (REF), U2.1 (OUT)
/SCLK: J6.1 (Pin_1_1), U6.4 (SCL/SPC)
/extRef: J8.1 (Pin_1_1), R14.1
GND: C1.2, C2.2, C6.2, C7.1, C9.2, C11.2, C12.2, C14.2, C15.2, J2.1 (Pin_1_1), R2.2, R12.2, U1.4 (V-), U2.2 (V-), U3.2 (GND), U4.2 (V-), U5.3 (A), U6.5 (GND), U6.10 (RES), U6.12 (GND)
unnamed: R6.2, R7.1, U1.1 (RG)
unnamed: C8.2, R8.1, U2.4 (-IN)
unnamed: C10.2, R9.1, U4.3 (+IN)
unnamed: C13.1, R10.2, R11.1, U4.4 (-IN)
unnamed: R1.2, R2.1, U5.1 (R)
Vref: C1.1, C2.1, C4.2, C5.1, J12.1 (Pin_1_1), R1.1, R3.2, R9.2, R10.1, R13.2, R14.2, U2.3 (+IN), U5.2 (K)

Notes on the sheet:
Com. connection
Crystal 4.096MHz
Accelerometer + ADC
Voltage regulator
EMG INA331

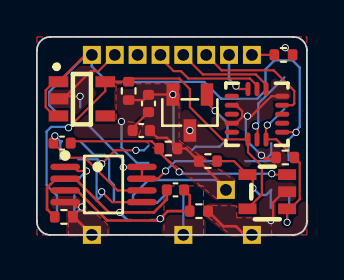
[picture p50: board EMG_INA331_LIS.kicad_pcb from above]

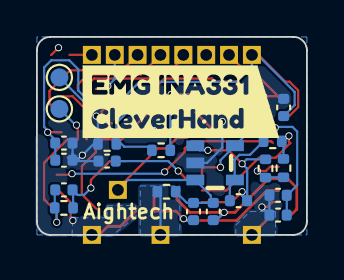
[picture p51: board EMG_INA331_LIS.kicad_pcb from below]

Board: 4 copper layers, 15.0 x 11.0 mm, 50 parts (22 on the bottom side), 23 nets.

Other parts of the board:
kibuzzard-6606B2BA: G***; kibuzzard-6606B2BA

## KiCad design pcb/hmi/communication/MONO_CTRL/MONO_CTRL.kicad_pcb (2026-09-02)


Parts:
AE1: Antenna_Chip; C_1206_3216Metric; LCSC C6807751
C1, C3, C12: 3.3pF; C_0402_1005Metric
C2, C8, C9: 1uF; C_0402_1005Metric
C4: 22pF; C_0402_1005Metric; LCSC C12530
C5: 22pF; C_0402_1005Metric; LCSC C1532
C6: 10uF; C_0402_1005Metric
C7, C10: 0.1uF; C_0402_1005Metric
I1: smd_insert; insert_1.2mm
J1, J2, J4, J5, J6, J7, J8, J9, J10, J11, J12, J13, J14, J15, J16, J17, J18, J19, J20, J21, J22, J23, J24, J25, J26: Conn_01x01_Pin; PinHeader_1x01_P1.27mm_Vertical
L1: 2.2nH; L_0402_1005Metric
LED1: WS2812C-2020-V1; LED-SMD_4P-L2.0-W2.0-TL_WS2812B-2020; LCSC Part C2976072
LED2: WS2812C; LED-SMD_4P-L2.0-W2.0-TL_WS2812B-2020; LCSC Part C2976072
R1: 10K; R_0402_1005Metric; LCSC C25744
R2: 47.5k; R_0402_1005Metric; LCSC C25762
R3: 1M; R_0402_1005Metric; LCSC C25762
R4, R5: 10k; R_0402_1005Metric; LCSC C25762
R6: 250K; R_0402_1005Metric; LCSC C25762
SW1: TS-1088R-02026; SW-SMD_L3.9-W3.0-P4.45; LCSC Part C455280
SW2: SW-SMD_L3.9-W3.0-P4.45; LCSC C720477
U1: MCP73831/2; SOT-23-5; LCSC C14879
U2: ESP32-C3FH4; PARTREV V1.0; LCSC C2858491
U3: MIC5504; UDFN-4-1EP_1x1mm_P0.65mm_EP0.48x0.48mm; LCSC C3021135
Y1: XTAL_40MHz; Crystal_SMD_2016-4Pin_2.0x1.6mm; LCSC C2929402

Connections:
+3.3V: C6.1, C7.1, C9.1, C10.1, J1.1, J11.1, LED1.4 (VDD), LED2.4 (VDD), R1.1, R4.1, R5.2, U2.2 (VDD3P3), U2.3 (VDD3P3), U2.11 (VDD3P3_RTC), U2.17 (VDD3P3_CPU), U2.31 (VDDA), U2.32 (VDDA), U3.1 (VOUT)
+5V: J4.1, U1.4 (V_{DD})
+BATT: C2.1, C8.1, J24.1, R3.2, U1.3 (V_{BAT}), U3.3 (EN), U3.4 (VIN)
/ADC_BATT: R3.1, R6.1, U2.10 (MTDI)
/BAT_PRG: R2.2, U1.5 (PROG)
/CSB: J8.1, U2.13 (MTDO)
/ESP_EN: R5.1, U2.6 (GPIO2), U2.7 (CHIP_EN)
/GPIO: J21.1, R1.2, SW1.1, U2.4 (XTAL_32K_P)
/GPIO8: J7.1, J14.1, U2.14 (GPIO8)
/GPIO9: J5.1, J12.1, U2.15 (GPIO9)
/LED_IN: LED2.3 (DI), U2.12 (MTCK)
/PICO: J6.1, J13.1, U2.16 (GPIO10)
/PWM: J18.1, U2.5 (XTAL_32K_N)
/SPICS: J15.1, U2.8 (GPIO3)
/STATUS_CHARGER: U1.1 (STAT)
/U0RX: J16.1, U2.27 (U0RXD)
/U0TX: J17.1, U2.28 (U0TXD)
/USB_D+: J10.1, U2.26 (GPIO19)
/USB_D-: J23.1, U2.25 (GPIO18)
/XTAL_N: C4.1, U2.29 (XTAL_N), Y1.1
/XTAL_P: C5.1, U2.30 (XTAL_P), Y1.3
/antena: AE1.1 (FEED), C1.1, C12.1, L1.1
/extRef: J9.1
/lna_in: C3.1, C12.2, L1.2, U2.1 (LNA_IN)
GND: C1.2, C2.2, C3.2, C4.2, C5.2, C6.2, C7.2, C8.2, C9.2, C10.2, I1.1 (conn), J2.1, J22.1, J25.1, J26.1, LED1.2 (GND), LED2.2 (GND), R2.1, R6.2, SW1.2, SW2.1, U1.2 (V_{SS}), U2.33 (GND), U3.2 (GND), Y1.2, Y1.4
unnamed: LED1.3 (DI), LED2.1 (DO)
unnamed: R4.2, SW2.2, U2.9 (MTMS)

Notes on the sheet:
Battery charging
Insert attach pad
NEOPIXELS
MCU - ESP32-C3
Com. connection
GPIO button
Tension regulator
Battery
Ext. IO
Ext. port



Board: 4 copper layers, 15.0 x 13.9 mm, 53 parts (8 on the bottom side), 25 nets.

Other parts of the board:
kibuzzard-66D6133A: G***; kibuzzard-66D6133A
kibuzzard-658C2757: G***; kibuzzard-658C2757

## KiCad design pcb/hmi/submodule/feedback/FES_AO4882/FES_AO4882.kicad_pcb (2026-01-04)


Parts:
C1: 4.7uF; C_0402_1005Metric; LCSC C23733
J1, J2, J3, J4, J5, J6, J7, J8, J15, J16, J17, J24: Conn_01x01_Pin; PinHeader_1x01_P1.27mm_Vertical
J9, J10, J18, J19: Conn_01x01_Pin; TestPoint_Pad_D1.0mm
J11, J12, J13, J14, J20, J21, J22, J23: Conn_01x01_Pin; PinHeader_1x01_P1.27mm_Vertical; not fitted
Q1, Q2: AO4882_C3040598; SOIC-8_L4.9-W3.9-P1.27-LS6.0-BL; LCSC Part C3040598
R1, R3, R6, R7: 1k; R_0402_1005Metric
R2: 10K; R_0402_1005Metric; LCSC C25744
R4, R5, R8, R9: 2k; R_0402_1005Metric
SW1: TS-1088R-02026; SW-SMD_L3.9-W3.0-P4.45; LCSC Part C455280
U1, U2, U3, U5: DS12W-MS; SOD-123FL_L2.7-W1.8-LS3.8-RD; LCSC Part C5120757
U4: HC32L110C6UA-SFN20TR; WQFN-20_L3.0-W3.0-P0.40-BL-EP; LCSC Part C493490

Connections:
+3.3V: J1.1, R2.2, U4.6 (AVCC)
/AIN0: U4.11 (AIN0)
/FES1in: J11.1, U3.1 (C)
/FES1out: J12.1, Q1.7 (D1), Q1.8 (D1)
/FES2in: J13.1, U2.1 (C)
/FES2out: J14.1, Q1.5 (D2), Q1.6 (D2)
/FES3in: J20.1, U5.1 (C)
/FES3out: J21.1, Q2.7 (D1), Q2.8 (D1)
/FES4in: J22.1, U1.1 (C)
/FES4out: J23.1, Q2.5 (D2), Q2.6 (D2)
/GPIO: R2.1, SW1.1, U4.20 (GPIO)
/IO1_in: U4.3 (GPIO)
/PICO_ARM: J5.1, U4.13 (SPI_PICO)
/PWM1: J9.1, R1.1, U4.10 (PCA_CH0)
/PWM1_: Q1.2 (G1), R1.2, R4.2
/PWM2: J10.1, R3.1, U4.7 (PCA_CH3)
/PWM2_: Q1.4 (G2), R3.2, R5.2
/PWM3: J18.1, R6.1, U4.17 (PCA_CH1)
/PWM3_: Q2.2 (G1), R6.2, R8.2
/PWM4: J19.1, R7.1, U4.16 (PCA_CH2)
/PWM4_: Q2.4 (G2), R7.2, R9.2
/SCLK_ARM: J6.1, U4.12 (SPI_SCK)
/SPICS_ARM: J7.1, U4.9 (SPI_CS)
/SWCLK: J15.1, U4.15 (SWCLK)
/SWDIO/POCI_ARM: J4.1, J16.1, U4.14 (SWDIO)
/Vcap: C1.2, U4.5 (Vcap)
/addr_mod_0: U4.18 (GPIO)
/extRef: J8.1
GND: C1.1, J2.1, J17.1, Q1.1 (S1), Q1.3 (S2), Q2.1 (S1), Q2.3 (S2), R4.1, R5.1, R8.1, R9.1, SW1.2, U4.4 (AVSS), U4.21 (EPAD)
VCC: J24.1, U1.2 (A), U2.2 (A), U3.2 (A), U5.2 (A)

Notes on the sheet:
ARM HC32L110
Com. connection
FES x4
IO button
Programming pins
Ext. power supply



Board: 4 copper layers, 15.0 x 11.0 mm, 42 parts (3 on the bottom side), 26 nets.

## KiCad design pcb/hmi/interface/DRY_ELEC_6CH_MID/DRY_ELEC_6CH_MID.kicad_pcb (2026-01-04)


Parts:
J1, J2, J3, J4, J5, J6, J7, J8, J9, J10, J11, J12, J13, J14, J15, J16: Conn_01x01_Pin; SolderWirePad_1x01_SMD_1x2mm
J17, J18, J19, J20, J21, J22: Conn_01x01_Pin; Pin_D1.2mm_pogo

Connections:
/IN1: J7.1, J8.1, J15.1, J16.1; also elsewhere on the board
/IN2: J6.1, J14.1; also elsewhere on the board
/IN3: J5.1, J13.1; also elsewhere on the board
/IN4: J4.1, J12.1; also elsewhere on the board
/IN5: J3.1, J11.1; also elsewhere on the board
/IN6: J2.1, J10.1; also elsewhere on the board
/filtering_1/ELECTRODE: J17.1; also elsewhere on the board
/filtering_2/ELECTRODE: J18.1; also elsewhere on the board
/filtering_3/ELECTRODE: J19.1; also elsewhere on the board
/filtering_4/ELECTRODE: J20.1; also elsewhere on the board
/filtering_5/ELECTRODE: J21.1; also elsewhere on the board
/filtering_6/ELECTRODE: J22.1; also elsewhere on the board
GND: J1.1, J9.1; also elsewhere on the board


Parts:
C1, C2: C; C_0402_1005Metric
JP1: SolderJumper_2_Bridged; SolderJumper-2_P1.3mm_Bridged_RoundedPad1.0x1.5mm
R1, R2: R; R_0402_1005Metric_Pad0.72x0.64mm_HandSolder

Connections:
/IN1: C2.1, JP1.2 (B), R2.2; also elsewhere on the board
/filtering_1/ELECTRODE: JP1.1 (A), R1.1; also elsewhere on the board
GND: C1.2, C2.2; also elsewhere on the board
unnamed: C1.1, R1.2, R2.1

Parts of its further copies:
C3, C4, C5, C6, C7, C8, C9, C10, C11, C12: C; C_0402_1005Metric
JP2, JP3, JP4, JP5, JP6: SolderJumper_2_Bridged; SolderJumper-2_P1.3mm_Bridged_RoundedPad1.0x1.5mm
R3, R4, R5, R6, R7, R8, R9, R10, R11, R12: R; R_0402_1005Metric_Pad0.72x0.64mm_HandSolder

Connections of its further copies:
/IN2: C4.1, JP2.2 (B), R4.2; also elsewhere on the board
/IN3: C6.1, JP3.2 (B), R6.2; also elsewhere on the board
/IN4: C8.1, JP4.2 (B), R8.2; also elsewhere on the board
/IN5: C10.1, JP5.2 (B), R10.2; also elsewhere on the board
/IN6: C12.1, JP6.2 (B), R12.2; also elsewhere on the board
/filtering_2/ELECTRODE: JP2.1 (A), R3.1; also elsewhere on the board
/filtering_3/ELECTRODE: JP3.1 (A), R5.1; also elsewhere on the board
/filtering_4/ELECTRODE: JP4.1 (A), R7.1; also elsewhere on the board
/filtering_5/ELECTRODE: JP5.1 (A), R9.1; also elsewhere on the board
/filtering_6/ELECTRODE: JP6.1 (A), R11.1; also elsewhere on the board
GND: C3.2, C4.2, C5.2, C6.2, C7.2, C8.2, C9.2, C10.2, C11.2, C12.2; also elsewhere on the board
unnamed: C3.1, R3.2, R4.1
unnamed: C5.1, R5.2, R6.1
unnamed: C7.1, R7.2, R8.1
unnamed: C9.1, R9.2, R10.1
unnamed: C11.1, R11.2, R12.1

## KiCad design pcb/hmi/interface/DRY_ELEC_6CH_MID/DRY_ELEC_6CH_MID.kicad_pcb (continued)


Board: 4 copper layers, 30.0 x 11.0 mm, 53 parts (0 on the bottom side), 19 nets.

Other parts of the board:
kibuzzard-66BB0EE4: G***; kibuzzard-66BB0EE4

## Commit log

2021-08-24 v7-panel
    smd0201
    [clvHd-Panel.brd]
2021-08-29 jst sh conn
    [clvHd.brd, clvHd.sch]
2021-08-29 dim changed to be panalized 3x4
    [clvHd.brd]
2021-09-24 gnd-vdd common
    [clvHd.brd, clvHd.sch]
2021-09-25 component val + minor debug
    [clvHd.brd, clvHd.sch, clvHd_top_bom.csv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]
2021-09-26 update colors + text
    [clvHd.brd, clvHd.sch]
2021-09-27 correction led
    [clvHd.brd, clvHd.sch]
2021-10-28 Xtal fixed + logo
    [clvHd.brd, clvHd.sch]
2021-11-08 added master FES EMG folders
    [acq05.brd, acq05.sch, acq06.brd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]
2021-11-26 almost fully routed
    [clvHd_EMG.brd, clvHd_EMG.sch]
2021-11-27 ready for prod
    [BM02B-SRSS-TB.step.SLDPRT, BM03B-SRSS-TB.step.SLDPRT, C0402.step.SLDPRT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]
2021-11-30 master update
    [clvHd_EMG.brd, clvHd_Master.brd, clvHd_Master.sch]
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2021-12-16 dir indication + lvl3 gnd plane
    [clvHd_EMG.brd, clvHd_EMG.sch]
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2022-07-01 nand new package
    changed the json package for a vssop package to make is easier to solder. updated README, docs and CAM
    [clvHd_EMG.brd, clvHd_EMG.sch]
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2022-07-31 fixed g00 pinout
    [clvHd_EMG.brd, clvHd_EMG.sch]
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2022-10-31 fixed some panel bug for jlcpcb
    [BOM-panel.csv, cleverhand_emg.kicad_pcb, cleverhand_emg.kicad_sch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]
2022-11-01 v3.1 fixed solder and paste mask and some via pos
    [BOM-cleverhand_emg.csv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]
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2023-02-22 new module with hc32l110 and some extension board
    [ads1293_logic_add.kicad_pcb, ads1293_logic_add.kicad_sch, bridge.kicad_pcb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]
2023-05-29 lot of modification, preparing a refactor + some rendering
    [ADS1293CISQE_0402_unit.kicad_sch, BOM-bridge.csv, BOM-hc32l110.csv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]
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2023-11-15 new version logicGate+hc32l to mitigate CS speed while keeping new features
    [ADS1293CISQE_0402_unit.kicad_sch, ads1293_unit.kicad_sch, comBusIN_v2.kicad_sch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]
2023-11-28 new modules EMGDAQ and COMMOD
    [COM_MOD.kicad_pcb, COM_MOD.kicad_sch, EMG_DAQ_ADS1293.kicad_pcb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]
2023-11-30 reshaped the modules boards sizes
    [COM_MOD.step, DRY_ELECTRODES.kicad_pcb, DRY_ELECTRODES.kicad_sch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]
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2023-12-05 some cleaning + edge plating dry electrode
    [COM_MOD.kicad_pcb, COM_MOD.kicad_sch, DRY_ELECTRODES.kicad_pcb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]
2023-12-07 finished rooting emgdaq + schematic commod
    [COM_MOD.kicad_pcb, COM_MOD.kicad_sch, DRY_ELECTRODES.kicad_pcb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]
2023-12-30 lot of updates on ads93,flex,commod,pad
    [BOM-COM_MOD.csv, BOM-DRY_ELECTRODES.csv, BOM-EMG_DAQ_ADS1293.csv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]
2024-01-02 finished ads93,commod,drypad,flexpad,jackconn,imubno + plot and render
    [BOM-COM_MOD.csv, BOM-IMU_BNO085.csv, BOM-JACK_CONN.csv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]
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2024-03-30 refactor and fixing most of the modules
    [BOM-FES_AO4882.csv, COM_MOD.kicad_pcb, COM_MOD.kicad_sch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]
2024-03-30 new dry flex
    [DRY_FLEX-B_Cu.gbl, DRY_FLEX-B_Mask.gbs, DRY_FLEX-B_Paste.gbp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]
2024-03-30 cleaned all modules + production files
    [BOM-COM_MOD.csv, BOM-DRY_ELECTRODES.csv, BOM-EMG_DAQ_ADS1293.csv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]
2024-04-01 fixed INA331 wrong package and add ext ref
    [EMG_INA331.kicad_pcb, EMG_INA331.kicad_sch]
2024-04-01 regenerated production files for INA331
    [COM_MOD.stl, DRY_ELECTRODES.stl, DRY_FLEX.stl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]
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2024-06-24 fixed COM_MOD grounding issues
    [BOM-COM_MOD.csv, BOM-EMG_DAQ_ADS1293.csv, BOM-PANEL_COM_MOD.csv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]
2024-07-28 minor update: added pins to access i2c pins of the com bus
    [COM_MOD.kicad_pcb, COM_MOD.kicad_sch]
2024-07-28 major update: fixed inversion of i2c lines + added pull up resistors + rotated 180deg fpc conector
    [CONTROLLER_teensy4.kicad_pcb, CONTROLLER_teensy4.kicad_sch]
2024-07-29 fixed ref number of FPC connectors and added ref numbers of resitors
    [CONTROLLER_teensy4.kicad_pcb, CONTROLLER_teensy4.kicad_sch]
2024-08-17 modified pins to expose in6 and gnd for potential filtering
    [CPL-PANEL_ADS1293.csv, EMG_DAQ_ADS1293-CuBottom.gbr, EMG_DAQ_ADS1293-CuIn1.gbr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]
2024-08-17 increase size of the board to make it easier to screw
    [CPL-JACK_CONN.csv, JACK_CONN-CuBottom.gbr, JACK_CONN-CuIn1.gbr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]
2024-08-17 new dry electectrodes for ads1295 module
    [BOM-DRY_ELEC_6CH.csv, BOM-DRY_ELEC_6CH_THIN.csv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]
2024-08-17 pannel for new dry electrodes
    [BOM-PANEL_DRY_ELEC_6CH_THIN.csv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]
2024-08-25 v3.2 fixed issue between GND and GNDA
    [BOM-EMG_DAQ_ADS1293.csv, BOM-PANEL_ADS1293.csv, EMG_DAQ_ADS1293.kicad_pcb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]
2024-08-26 update production files of shield controller teensy
    [BOM-CONTROLLER_teensy4.csv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]
2024-09-02 mono controller, to have module working on their own and comunicate via wifi
    [MONO_CTRL.kicad_pcb, MONO_CTRL.kicad_sch]
2024-09-02 finished mono moudule, should be ready for manufacture
    [MONO_CTRL.kicad_pcb, MONO_CTRL.kicad_sch]
2024-09-02 fixed pico controller shield to match v3 modules
    [CONTROLLER_pico.kicad_pcb, CONTROLLER_pico.kicad_sch]
2024-09-02 minor fix on teensy shield
    [CONTROLLER_teensy4.kicad_pcb, CONTROLLER_teensy4.kicad_sch]
2024-09-03 fixed MONOCOM ERC and DRC: via size, missing pins
    [MONO_CTRL.kicad_pcb, MONO_CTRL.kicad_sch]
2024-09-04 generated production files and plots of controllers shield and mono ctrl
    [BOM-CONTROLLER_pico.csv, BOM-CONTROLLER_teensy4.csv, BOM-MONO_CTRL.csv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]
2024-10-08 added 2x2 panels for COM_MOD and EMD_ADS1293
    [BOM-PANEL2x2_ADS1293.csv, BOM-PANEL5x4_COM_MOD.csv, BOM-PANEL7x5_ADS1293.csv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]
2024-10-12 fixed castelated holes for beter fixation on interface board
    [COM_MOD.kicad_pcb, COM_MOD.kicad_sch]
2024-10-12 added mid size to fit better with ads1293 module and standad xtal + some modificaion
    [DRY_ELEC_6CH.kicad_pcb, DRY_ELEC_6CH_MID.kicad_pcb, DRY_ELEC_6CH_MID.kicad_sch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]
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2024-10-12 added doc and regenerated gerbers
    [BOM-COM_MOD.csv, BOM-DRY_ELEC_6CH_MID.csv, BOM-PANEL2x2_COM_MOD.csv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]
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2025-03-25 some work on mono controller
    [COM_MOD.kicad_pcb, MONO_CTRL.step]
2026-01-04 refactoring and redocumenting all modules
    [ADS1293CISQE_0402_unit.kicad_sch, BOM-BUS_CONN.csv, BOM-COM_MOD.csv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]
2026-09-02 chore(kicad): migrate S_XIAO, COM_MOD, DRY_ELEC_16CH and ADS1293 to KiCad 10
    File format bump only: version 20250114 -> 20260306, generator_version
    9.0 -> 10.0. The project files gain the new KiCad 10 default keys (zone
    fill parameters, extra DRC/ERC severity entries). COM_MOD.kicad_sch has
    an identical component set before and after -- no design change.
    Claude-Session: https://claude.ai/code/session_01Fp1CWL3JE8kAHQpHzFCsU5
    [COM_MOD.kicad_sch]
2026-09-02 feat(EMG_INA331): drop the LIS3DH, keep the module INA331-only
    The accelerometer moves out to the new EMG_INA331_LIS variant so that
    EMG_INA331 is a plain analog EMG front-end usable with any ADC-capable
    com module. All 7 LIS3DH references are gone from the schematic.
    Also fixes the outstanding ERC issues: U6 pin 13 (ADC3) is no longer
    dangling and the power symbols are re-synced with the library, taking
    the report from 6 errors / 55 warnings down to 5 / 23. DRC stays at 0
    violations. Plots, PDF, SVG and DRC/ERC logs regenerated under KiCad 10.
    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
    [EMG_INA331.kicad_pcb, EMG_INA331.kicad_sch]
2026-09-02 feat(MONO_CTRL): add J19/J20 test pins, migrate to KiCad 10
    Adds two Conn_01x01_Pin connectors (J19, J20) to the schematic.
    Note: the layout does not carry them yet -- MONO_CTRL.kicad_pcb still
    holds the same 51 footprints as before, so schematic and PCB are out of
    sync until the board is updated from the schematic.
    The rest of the diff is the KiCad 9 -> 10 file format bump.
    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
    [MONO_CTRL.kicad_pcb, MONO_CTRL.kicad_sch]
2026-09-02 feat(EMG_INA331_LIS): add the INA331 + LIS3DH variant
    Counterpart of the EMG_INA331 split: this variant keeps the LIS3DH
    accelerometer alongside the INA331 EMG front-end.
    The directory was seeded by copying EMG_INA331, so this commit also
    cleans up what the copy dragged along:
    - description.yaml now carries its own id, name, sku, model, subtype
    and image instead of duplicating EMG_INA331's SKU
    - README points at the EMG_INA331_LIS plots rather than the broken
    EMG_INA331 paths
    - dropped the stale EMG_INA331_* PNGs, zip and pcb_svg files (~1.9 MB
    of duplicates of the other module)
    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
    [BOM-EMG_INA331_LIS.csv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]
2026-09-02 feat: add XIAO_COM, EMG_DAQ_ADS1292, v2/emgvib and flexBracelet
    Four new boards, all authored with KiCad 10:
    - hmi/communication/XIAO_COM: XIAO-based com module (README, HARDWARE.md,
    plots, gerbers, STEP/STL)
    - hmi/submodule/sensor/EMG_DAQ_ADS1292: ADS1292 EMG front-end with an
    electrodeFilter sub-sheet. Its README and description.yaml were copied
    from the ADS1293 module and still named that chip -- corrected here.
    - hmi/submodule/v2/emgvib: combined EMG + vibration submodule
    - tool/flexBracelet: flex bracelet with JLCPCB production files
    Still missing and left for a follow-up: description.yaml for XIAO_COM,
    and README + description.yaml for emgvib and flexBracelet.
    Claude-Session: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
    [BOM-XIAO_ADAPTER.csv, BOM-XIAO_COM.csv, BOM-flexBracelet.csv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]
